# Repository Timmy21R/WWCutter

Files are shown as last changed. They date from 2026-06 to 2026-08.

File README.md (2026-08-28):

# WWCutter

Cross-platform four-axis hot-wire CAM and machine controller. It imports a
STEP solid or shell, finds (or lets the user select) its two end sections,
verifies that straight wire rulings reproduce the CAD surface, projects those
rulings to the XY and UV towers, and previews the complete machine motion.

## Setup

Python 3.11 or newer is recommended on Windows, macOS, and Linux.

```bash
conda activate foamcut
python -m pip install -r requirements.txt
python WWCutterV01.py
```

CadQuery includes Open Cascade and reads STEP units as millimetres. No native
compiler or platform-specific application changes are required when its wheel
is available for the selected Python version.

## STEP workflow

1. Select **Import STEP**. Ordinary two-section lofts are detected
   automatically.
2. If necessary, select different root and tip sections from their dropdowns.
   Open-shell boundary loops are also available in the two section lists.
3. Enter the tower spacing, distance from the left tower to the root face, and
   horizontal/vertical travel. Set the stock rotation about its span axis and
   its root-section center in the machine workspace. Stock-position controls
   are constrained to the range where both complete tower paths remain inside
   the configured travel and safety margin. Choose whether internal contours
   are ignored or cut through an entry slit.
4. Choose **Resulting cut surface** to inspect the complete surface swept by
   the physical wire, or **Complete machine** to see it in the tower workspace.
   Move the slider to inspect every individual wire position. Green and blue
   mark the two foam sections or tower paths; yellow is the current wire.
   Dense models are shown at reduced detail while rotating; this affects only
   the display, not the calculated cut.
5. With the heater off, use **Move to Cut Start** to perform the dashed
   positioning move shown in the machine preview.
6. A STEP job can start only when its measured ruled-surface deviation is no
   greater than the configured tolerance and all projected moves fit the
   workspace.

The **Manual axes / job origin** fields provide the four X, Y, U, and V target
coordinates used by **Go to Origin**. **Set Current as Origin** resets the
controller's current four-axis position and all four fields to zero. These
manual values do not offset or bypass validation of the generated STEP path.

Deviation is checked in both directions at intermediate span sections. This
catches STEP skins that bow between otherwise valid root and tip profiles—a
straight hot wire can create only a ruled surface. Ignored internal contours
do not contribute motion or deviation, and the preview labels the measurement
as outer-only. Through contours can be cut with an entry slit; blind contours
that do not reach both foam end faces remain blocked.

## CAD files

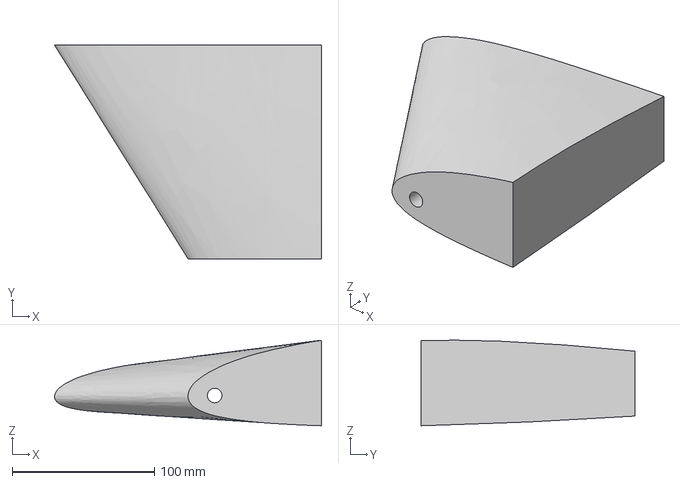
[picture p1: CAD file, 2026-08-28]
MasterSections.step
187.5 x 150.0 x 60.1 mm

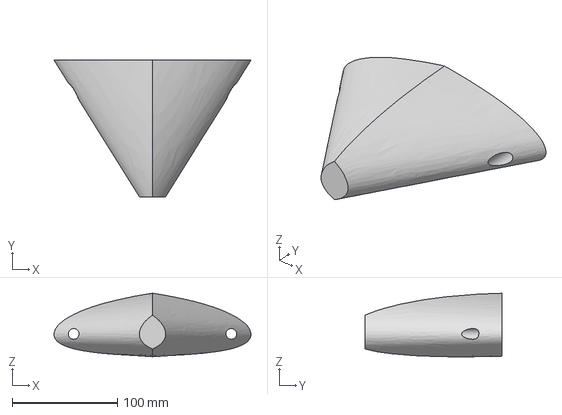
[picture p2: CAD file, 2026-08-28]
MasterSections12.step
187.5 x 130.0 x 60.5 mm

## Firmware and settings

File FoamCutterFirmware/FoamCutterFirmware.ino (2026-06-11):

#include <AccelStepper.h>
#include <MultiStepper.h>
#include <ctype.h>
#include <stdlib.h>
#include <string.h>

// Step/dir pins (CNC shield)
AccelStepper stepperX(AccelStepper::DRIVER, 2, 5);
AccelStepper stepperY(AccelStepper::DRIVER, 3, 6);
AccelStepper stepperU(AccelStepper::DRIVER, 4, 7);
AccelStepper stepperV(AccelStepper::DRIVER, 12, 13);
MultiStepper steppers;

// IO
#define ENABLE_PIN 8
#define X_LIMIT_PIN 9
#define Y_LIMIT_PIN 10
#define U_LIMIT_PIN 11
#define V_LIMIT_PIN A3

struct MachineConfig {
  long cutMaxSpeed = 2500;       // steps/sec
  long homeSpeed = 3200;         // steps/sec
  int homeDirection = -1;        // -1 or +1
  uint8_t homeSensorX = 0;       // 0=X, 1=Y, 2=U, 3=V
  uint8_t homeSensorY = 1;
  uint8_t homeSensorU = 2;
  uint8_t homeSensorV = 3;
};

struct MoveTarget {
  long x;
  long y;
  long u;
  long v;
  int speed;
};

MachineConfig config;
long positions[4];
const uint8_t MOVE_QUEUE_CAPACITY = 45;
const uint8_t MAX_INPUT_LINE_LENGTH = 64;
const unsigned long HOME_SWITCH_DEBOUNCE_MS = 10;
const unsigned long HOME_TIMEOUT_MS = 120000;
const unsigned long HOME_STATUS_INTERVAL_MS = 100;
MoveTarget moveQueue[MOVE_QUEUE_CAPACITY];
uint8_t moveQueueHead = 0;
uint8_t moveQueueTail = 0;
uint8_t moveQueueCount = 0;
bool moveActive = false;
bool motionPaused = false;
bool uploadJobActive = false;
long uploadExpectedMoves = 0;
long uploadAcceptedMoves = 0;
long uploadCompletedMoves = 0;
MoveTarget activeMove;

void enableDrivers() {
  digitalWrite(ENABLE_PIN, LOW);
}

void releaseDrivers() {
  digitalWrite(ENABLE_PIN, HIGH);
}

void trimInPlace(char *value) {
  if (!value) return;

  size_t length = strlen(value);
  size_t start = 0;
  while (start < length && isspace((unsigned char)value[start])) {
    start++;
  }

  size_t end = length;
  while (end > start && isspace((unsigned char)value[end - 1])) {
    end--;
  }

  if (start > 0) {
    memmove(value, value + start, end - start);
  }
  value[end - start] = '\0';
}

void toUpperInPlace(char *value) {
  if (!value) return;
  while (*value) {
    *value = (char)toupper((unsigned char)*value);
    value++;
  }
}

bool parseLongValue(const char *value, long &outValue) {
  if (!value) return false;
  while (*value && isspace((unsigned char)*value)) {
    value++;
  }
  if (*value == '\0') return false;

  char *endPtr = nullptr;
  long parsed = strtol(value, &endPtr, 10);
  if (endPtr == value) return false;
  while (*endPtr) {
    if (!isspace((unsigned char)*endPtr)) {
      return false;
    }
    endPtr++;
  }
  outValue = parsed;
  return true;
}

bool limitTriggered(int pin) {
  return digitalRead(pin) == HIGH;
}

void printStatus() {
  Serial.print(F("OK STATUS X="));
  Serial.print(limitTriggered(X_LIMIT_PIN) ? 1 : 0);
  Serial.print(F(" Y="));
  Serial.print(limitTriggered(Y_LIMIT_PIN) ? 1 : 0);
  Serial.print(F(" U="));
  Serial.print(limitTriggered(U_LIMIT_PIN) ? 1 : 0);
  Serial.print(F(" V="));
  Serial.println(limitTriggered(V_LIMIT_PIN) ? 1 : 0);
}

void applyCutSpeed() {
  long speed = config.cutMaxSpeed;
  if (speed < 100) speed = 100;
  stepperX.setMaxSpeed(speed);
  stepperY.setMaxSpeed(speed);
  stepperU.setMaxSpeed(speed);
  stepperV.setMaxSpeed(speed);
}

void printConfig() {
  Serial.print(F("CFG cutMaxSpeed=")); Serial.println(config.cutMaxSpeed);
  Serial.print(F("CFG homeSpeed=")); Serial.println(config.homeSpeed);
  Serial.print(F("CFG homeDirection=")); Serial.println(config.homeDirection);
  Serial.print(F("CFG homeSensorX=")); Serial.println(config.homeSensorX);
  Serial.print(F("CFG homeSensorY=")); Serial.println(config.homeSensorY);
  Serial.print(F("CFG homeSensorU=")); Serial.println(config.homeSensorU);
  Serial.print(F("CFG homeSensorV=")); Serial.println(config.homeSensorV);
  Serial.println(F("OK GETCFG"));
}

void setConfigValue(char *key, char *value) {
  trimInPlace(key);
  trimInPlace(value);
  toUpperInPlace(key);
  long parsed = 0;
  if (!parseLongValue(value, parsed)) {
    Serial.println(F("ERR CFG invalid-number"));
    return;
  }

  if (strcmp(key, "CUTMAXSPEED") == 0) {
    if (parsed < 100) parsed = 100;
    config.cutMaxSpeed = parsed;
    applyCutSpeed();
    Serial.print(F("OK CFG cutMaxSpeed=")); Serial.println(config.cutMaxSpeed);
    return;
  }
  if (strcmp(key, "HOMESPEED") == 0) {
    if (parsed < 100) parsed = 100;
    config.homeSpeed = parsed;
    Serial.print(F("OK CFG homeSpeed=")); Serial.println(config.homeSpeed);
    return;
  }
  if (strcmp(key, "HOMEDIRECTION") == 0) {
    config.homeDirection = parsed >= 0 ? 1 : -1;
    Serial.print(F("OK CFG homeDirection=")); Serial.println(config.homeDirection);
    return;
  }
  if (strcmp(key, "HOMESENSORX") == 0) {
    if (parsed < 0) parsed = 0;
    if (parsed > 3) parsed = 3;
    config.homeSensorX = parsed;
    Serial.print(F("OK CFG homeSensorX=")); Serial.println(config.homeSensorX);
    return;
  }
  if (strcmp(key, "HOMESENSORY") == 0) {
    if (parsed < 0) parsed = 0;
    if (parsed > 3) parsed = 3;
    config.homeSensorY = parsed;
    Serial.print(F("OK CFG homeSensorY=")); Serial.println(config.homeSensorY);
    return;
  }
  if (strcmp(key, "HOMESENSORU") == 0) {
    if (parsed < 0) parsed = 0;
    if (parsed > 3) parsed = 3;
    config.homeSensorU = parsed;
    Serial.print(F("OK CFG homeSensorU=")); Serial.println(config.homeSensorU);
    return;
  }
  if (strcmp(key, "HOMESENSORV") == 0) {
    if (parsed < 0) parsed = 0;
    if (parsed > 3) parsed = 3;
    config.homeSensorV = parsed;
    Serial.print(F("OK CFG homeSensorV=")); Serial.println(config.homeSensorV);
    return;
  }

  Serial.println(F("ERR CFG unknown-key"));
}

int limitPinForSensorIndex(int sensorIndex) {
  switch (sensorIndex) {
    case 0: return X_LIMIT_PIN;
    case 1: return Y_LIMIT_PIN;
    case 2: return U_LIMIT_PIN;
    case 3: return V_LIMIT_PIN;
    default: return X_LIMIT_PIN;
  }
}

bool parseMove(char *parts[], int offset, long coords[4]) {
  for (int i = 0; i < 4; i++) {
    if (!parseLongValue(parts[offset + i], coords[i])) {
      return false;
    }
  }
  return true;
}

int parseAxisIndex(char *value) {
  if (!value) {
    return -1;
  }

  trimInPlace(value);
  toUpperInPlace(value);
  if (strcmp(value, "X") == 0) return 0;
  if (strcmp(value, "Y") == 0) return 1;
  if (strcmp(value, "U") == 0) return 2;
  if (strcmp(value, "V") == 0) return 3;
  return -1;
}

long currentAxisPosition(int axisIndex) {
  switch (axisIndex) {
    case 0: return positions[0];
    case 1: return positions[1];
    case 2: return positions[2];
    case 3: return positions[3];
    default: return 0;
  }
}

void clearMoveQueue() {
  moveQueueHead = 0;
  moveQueueTail = 0;
  moveQueueCount = 0;
  moveActive = false;
  motionPaused = false;
  uploadJobActive = false;
  uploadExpectedMoves = 0;
  uploadAcceptedMoves = 0;
  uploadCompletedMoves = 0;
}

void syncStepperPositionsFromLogical() {
  stepperX.setCurrentPosition(positions[0]);
  stepperY.setCurrentPosition(positions[1]);
  stepperU.setCurrentPosition(positions[2]);
  stepperV.setCurrentPosition(positions[3]);
}

void syncLogicalPositionsFromSteppers() {
  positions[0] = stepperX.currentPosition();
  positions[1] = stepperY.currentPosition();
  positions[2] = stepperU.currentPosition();
  positions[3] = stepperV.currentPosition();
}

bool enqueueMove(long coords[4], long targetSpeed) {
  if (moveQueueCount >= MOVE_QUEUE_CAPACITY) {
    return false;
  }

  moveQueue[moveQueueTail].x = coords[0];
  moveQueue[moveQueueTail].y = coords[1];
  moveQueue[moveQueueTail].u = coords[2];
  moveQueue[moveQueueTail].v = coords[3];
  moveQueue[moveQueueTail].speed = targetSpeed; // <--- NEW
  
  moveQueueTail = (moveQueueTail + 1) % MOVE_QUEUE_CAPACITY;
  moveQueueCount++;
  return true;
}

bool dequeueMove(MoveTarget &target) {
  if (moveQueueCount == 0) {
    return false;
  }

  target = moveQueue[moveQueueHead];
  moveQueueHead = (moveQueueHead + 1) % MOVE_QUEUE_CAPACITY;
  moveQueueCount--;
  return true;
}

bool targetMatchesLogicalPosition(const MoveTarget &target) {
  return
    target.x == positions[0] &&
    target.y == positions[1] &&
    target.u == positions[2] &&
    target.v == positions[3];
}

void startNextQueuedMove() {
  if (motionPaused || moveActive || moveQueueCount == 0) {
    return;
  }

  while (moveQueueCount > 0 && !motionPaused && !moveActive) {
    if (!dequeueMove(activeMove)) {
      return;
    }

    if (targetMatchesLogicalPosition(activeMove)) {
      completeActiveMove();
      continue;
    }

    enableDrivers();
    positions[0] = activeMove.x;
    positions[1] = activeMove.y;
    positions[2] = activeMove.u;
    positions[3] = activeMove.v;
    
    // --- NEW: Apply the dynamic speed for this specific segment ---
    long stepSpeed = activeMove.speed;
    if (stepSpeed < 100) stepSpeed = 100;
    stepperX.setMaxSpeed(stepSpeed);
    stepperY.setMaxSpeed(stepSpeed);
    stepperU.setMaxSpeed(stepSpeed);
    stepperV.setMaxSpeed(stepSpeed);
    // --------------------------------------------------------------

    steppers.moveTo(positions);
    moveActive = true;
    return;
  }
}
void completeActiveMove() {
  moveActive = false;
  uploadCompletedMoves++;

  Serial.print(F("OK MOVE "));
  Serial.print(activeMove.x); Serial.print(",");
  Serial.print(activeMove.y); Serial.print(",");
  Serial.print(activeMove.u); Serial.print(",");
  Serial.println(activeMove.v);

  if (uploadJobActive &&
      uploadCompletedMoves >= uploadExpectedMoves &&
      moveQueueCount == 0) {
    uploadJobActive = false;
    Serial.print(F("OK UPDONE "));
    Serial.println(uploadCompletedMoves);
  }
}

void serviceMoveQueue() {
  if (motionPaused) {
    return;
  }

  if (!moveActive) {
    startNextQueuedMove();
  }

  if (!moveActive) {
    return;
  }

  if (!steppers.run()) {
    completeActiveMove();
    startNextQueuedMove();
  }
}

void pauseMotion() {
  motionPaused = true;
  Serial.println(F("OK PAUSE"));
}

void resumeMotion() {
  motionPaused = false;
  startNextQueuedMove();
  Serial.println(F("OK RESUME"));
}

void abortMotion() {
  syncLogicalPositionsFromSteppers();
  steppers.moveTo(positions);
  syncStepperPositionsFromLogical();
  clearMoveQueue();

  Serial.print(F("OK ABORT "));
  Serial.print(positions[0]); Serial.print(",");
  Serial.print(positions[1]); Serial.print(",");
  Serial.print(positions[2]); Serial.print(",");
  Serial.println(positions[3]);
}

void executeMove(long coords[4]) {
  if (coords[0] == positions[0] &&
      coords[1] == positions[1] &&
      coords[2] == positions[2] &&
      coords[3] == positions[3]) {
    Serial.print(F("OK MOVE "));
    Serial.print(coords[0]); Serial.print(",");
    Serial.print(coords[1]); Serial.print(",");
    Serial.print(coords[2]); Serial.print(",");
    Serial.println(coords[3]);
    return;
  }

  enableDrivers();
  positions[0] = coords[0];
  positions[1] = coords[1];
  positions[2] = coords[2];
  positions[3] = coords[3];

  steppers.moveTo(positions);
  steppers.runSpeedToPosition();

  Serial.print(F("OK MOVE "));
  Serial.print(positions[0]); Serial.print(",");
  Serial.print(positions[1]); Serial.print(",");
  Serial.print(positions[2]); Serial.print(",");
  Serial.println(positions[3]);
}

void jogAxis(int axisIndex, long delta) {
  if (axisIndex < 0 || axisIndex > 3) {
    Serial.println(F("ERR JOG invalid-axis"));
    return;
  }
  if (delta == 0) {
    Serial.println(F("ERR JOG zero-delta"));
    return;
  }

  enableDrivers();

  AccelStepper *stepper = nullptr;
  switch (axisIndex) {
    case 0: stepper = &stepperX; break;
    case 1: stepper = &stepperY; break;
    case 2: stepper = &stepperU; break;
    case 3: stepper = &stepperV; break;
    default: break;
  }

  if (!stepper) {
    Serial.println(F("ERR JOG invalid-axis"));
    return;
  }

  syncStepperPositionsFromLogical();
  const long target = positions[axisIndex] + delta;
  long speed = config.cutMaxSpeed;
  if (speed < 100) speed = 100;
  stepper->setCurrentPosition(positions[axisIndex]);
  stepper->setMaxSpeed(speed);
  stepper->moveTo(target);
  stepper->setSpeed(delta > 0 ? speed : -speed);

  while (stepper->distanceToGo() != 0) {
    stepper->runSpeedToPosition();
  }

  positions[axisIndex] = target;

  Serial.print(F("OK JOG "));
  Serial.print(positions[0]); Serial.print(",");
  Serial.print(positions[1]); Serial.print(",");
  Serial.print(positions[2]); Serial.print(",");
  Serial.println(positions[3]);
}

void syncPosition(long coords[4]) {
  positions[0] = coords[0];
  positions[1] = coords[1];
  positions[2] = coords[2];
  positions[3] = coords[3];

  stepperX.setCurrentPosition(positions[0]);
  stepperY.setCurrentPosition(positions[1]);
  stepperU.setCurrentPosition(positions[2]);
  stepperV.setCurrentPosition(positions[3]);
  clearMoveQueue();

  Serial.print(F("OK SETPOS "));
  Serial.print(positions[0]); Serial.print(",");
  Serial.print(positions[1]); Serial.print(",");
  Serial.print(positions[2]); Serial.print(",");
  Serial.println(positions[3]);
}

const uint8_t HOME_AXIS_SEEKING = 0;
const uint8_t HOME_AXIS_DEBOUNCING = 1;
const uint8_t HOME_AXIS_DONE = 2;

bool isHomeAxisDone(uint8_t state) {
  return state == HOME_AXIS_DONE;
}

void updateHomeAxis(AccelStepper &stepper,
                    int limitPin,
                    uint8_t &state,
                    unsigned long &debounceStartedAtMs) {
  if (state == HOME_AXIS_DONE) {
    return;
  }

  const bool limitActive = limitTriggered(limitPin);

  if (state == HOME_AXIS_DEBOUNCING) {
    if (!limitActive) {
      state = HOME_AXIS_SEEKING;
      debounceStartedAtMs = 0;
      stepper.setSpeed(config.homeDirection * config.homeSpeed);
      return;
    }

    if (millis() - debounceStartedAtMs >= HOME_SWITCH_DEBOUNCE_MS) {
      stepper.setSpeed(0);
      state = HOME_AXIS_DONE;
    }
    return;
  }

  if (limitActive) {
    stepper.setSpeed(0);
    if (HOME_SWITCH_DEBOUNCE_MS == 0) {
      state = HOME_AXIS_DONE;
    } else {
      state = HOME_AXIS_DEBOUNCING;
      debounceStartedAtMs = millis();
    }
    return;
  }

  stepper.runSpeed();
}

void homeMachine() {
  enableDrivers();
  const unsigned long homeStartedAtMs = millis();
  unsigned long lastHomeStatusAtMs = 0;

  const int xHomeLimitPin = limitPinForSensorIndex(config.homeSensorX);
  const int yHomeLimitPin = limitPinForSensorIndex(config.homeSensorY);
  const int uHomeLimitPin = limitPinForSensorIndex(config.homeSensorU);
  const int vHomeLimitPin = limitPinForSensorIndex(config.homeSensorV);

  stepperX.setMaxSpeed(config.homeSpeed);
  stepperY.setMaxSpeed(config.homeSpeed);
  stepperU.setMaxSpeed(config.homeSpeed);
  stepperV.setMaxSpeed(config.homeSpeed);

  // --- STAGE 1: Home X and U (Horizontal) ---
  stepperX.setSpeed(config.homeDirection * config.homeSpeed);
  stepperU.setSpeed(config.homeDirection * config.homeSpeed);
  
  uint8_t xState = limitTriggered(xHomeLimitPin) ? HOME_AXIS_DEBOUNCING : HOME_AXIS_SEEKING;
  uint8_t uState = limitTriggered(uHomeLimitPin) ? HOME_AXIS_DEBOUNCING : HOME_AXIS_SEEKING;
  
  unsigned long xDebounceStartedAtMs = xState == HOME_AXIS_DEBOUNCING ? homeStartedAtMs : 0;
  unsigned long uDebounceStartedAtMs = uState == HOME_AXIS_DEBOUNCING ? homeStartedAtMs : 0;

  while (!isHomeAxisDone(xState) || !isHomeAxisDone(uState)) {
    const unsigned long nowMs = millis();
    if (lastHomeStatusAtMs == 0 || nowMs - lastHomeStatusAtMs >= HOME_STATUS_INTERVAL_MS) {
      printStatus();
      lastHomeStatusAtMs = nowMs;
    }
    if (nowMs - homeStartedAtMs >= HOME_TIMEOUT_MS) {
      applyCutSpeed(); clearMoveQueue(); Serial.println(F("ERR HOME timeout")); return;
    }
    updateHomeAxis(stepperX, xHomeLimitPin, xState, xDebounceStartedAtMs);
    updateHomeAxis(stepperU, uHomeLimitPin, uState, uDebounceStartedAtMs);
  }

  // --- STAGE 2: Home Y and V (Vertical) ---
  stepperY.setSpeed(config.homeDirection * config.homeSpeed);
  stepperV.setSpeed(config.homeDirection * config.homeSpeed);
  
  uint8_t yState = limitTriggered(yHomeLimitPin) ? HOME_AXIS_DEBOUNCING : HOME_AXIS_SEEKING;
  uint8_t vState = limitTriggered(vHomeLimitPin) ? HOME_AXIS_DEBOUNCING : HOME_AXIS_SEEKING;
  
  unsigned long yDebounceStartedAtMs = yState == HOME_AXIS_DEBOUNCING ? millis() : 0;
  unsigned long vDebounceStartedAtMs = vState == HOME_AXIS_DEBOUNCING ? millis() : 0;

  while (!isHomeAxisDone(yState) || !isHomeAxisDone(vState)) {
    const unsigned long nowMs = millis();
    if (lastHomeStatusAtMs == 0 || nowMs - lastHomeStatusAtMs >= HOME_STATUS_INTERVAL_MS) {
      printStatus();
      lastHomeStatusAtMs = nowMs;
    }
    if (nowMs - homeStartedAtMs >= HOME_TIMEOUT_MS) {
      applyCutSpeed(); clearMoveQueue(); Serial.println(F("ERR HOME timeout")); return;
    }
    updateHomeAxis(stepperY, yHomeLimitPin, yState, yDebounceStartedAtMs);
    updateHomeAxis(stepperV, vHomeLimitPin, vState, vDebounceStartedAtMs);
  }

  // --- STAGE 3: Finalize ---
  stepperX.setCurrentPosition(0);
  stepperY.setCurrentPosition(0);
  stepperU.setCurrentPosition(0);
  stepperV.setCurrentPosition(0);
  positions[0] = 0; positions[1] = 0; positions[2] = 0; positions[3] = 0;
  
  applyCutSpeed();
  clearMoveQueue();
  printStatus();
  Serial.println(F("OK HOME"));
}

void dispatchLine(char *line) {
  trimInPlace(line);
  if (line[0] == '\0') {
    return;
  }

  char *parts[8];
  int partCount = 0;
  char *context = nullptr;
  char *token = strtok_r(line, ",", &context);
  while (token && partCount < 8) {
    trimInPlace(token);
    parts[partCount++] = token;
    token = strtok_r(nullptr, ",", &context);
  }
  if (partCount <= 0) return;

  char *command = parts[0];
  toUpperInPlace(command);
  long coords[4];

  // Backward-compatible raw move: X,Y,U,V
  if (partCount == 4 && parseMove(parts, 0, coords)) {
    executeMove(coords);
    return;
  }

  if (strcmp(command, "UPLOAD") == 0) {
    if (partCount < 2) {
      Serial.println(F("ERR UPLOAD invalid-format"));
      return;
    }

    long expected = 0;
    if (!parseLongValue(parts[1], expected) || expected <= 0) {
      Serial.println(F("ERR UPLOAD invalid-count"));
      return;
    }

    clearMoveQueue();
    uploadJobActive = true;
    uploadExpectedMoves = expected;
    Serial.print(F("OK UPLOAD "));
    Serial.print(uploadExpectedMoves);
    Serial.print(F(" CAP="));
    Serial.println(MOVE_QUEUE_CAPACITY);
    return;
  }

  if (strcmp(command, "QUEUE") == 0) {
    if (partCount < 5 || !parseMove(parts, 1, coords)) {
      Serial.println(F("ERR QUEUE invalid-format"));
      return;
    }
    
    // Default to the UI's base speed, but overwrite if Python sends a dynamic speed
    long targetSpeed = config.cutMaxSpeed; 
    if (partCount >= 6) {
        parseLongValue(parts[5], targetSpeed);
    }
    
    if (!uploadJobActive) {
      Serial.println(F("ERR QUEUE no-upload"));
      return;
    }
    if (uploadAcceptedMoves >= uploadExpectedMoves) {
      Serial.println(F("ERR QUEUE overflow"));
      return;
    }
    if (!enqueueMove(coords, targetSpeed)) {
      Serial.println(F("ERR QUEUE full"));
      return;
    }

    uploadAcceptedMoves++;
    Serial.print(F("OK QUEUE "));
    Serial.print(uploadAcceptedMoves);
    Serial.print("/");
    Serial.print(uploadExpectedMoves);
    Serial.print(F(" BUF="));
    Serial.println(moveQueueCount + (moveActive ? 1 : 0));
    startNextQueuedMove();
    return;
  }

  if (strcmp(command, "SETPOS") == 0) {
    if (partCount < 5 || !parseMove(parts, 1, coords)) {
      Serial.println(F("ERR SETPOS invalid-format"));
      return;
    }
    syncPosition(coords);
    return;
  }

  if (strcmp(command, "MOVE") == 0) {
    if (partCount < 5 || !parseMove(parts, 1, coords)) {
      Serial.println(F("ERR MOVE invalid-format"));
      return;
    }
    executeMove(coords);
    return;
  }

  if (strcmp(command, "JOG") == 0) {
    if (partCount < 3) {
      Serial.println(F("ERR JOG invalid-format"));
      return;
    }
    const int axisIndex = parseAxisIndex(parts[1]);
    long delta = 0;
    if (axisIndex < 0 || !parseLongValue(parts[2], delta)) {
      Serial.println(F("ERR JOG invalid-format"));
      return;
    }
    jogAxis(axisIndex, delta);
    return;
  }

  if (strcmp(command, "HOME") == 0) {
    homeMachine();
    return;
  }

  if (strcmp(command, "PAUSE") == 0) {
    pauseMotion();
    return;
  }

  if (strcmp(command, "RESUME") == 0) {
    resumeMotion();
    return;
  }

  if (strcmp(command, "ABORT") == 0) {
    abortMotion();
    return;
  }

  if (strcmp(command, "CFG") == 0) {
    if (partCount < 3) {
      Serial.println(F("ERR CFG invalid-format"));
      return;
    }
    setConfigValue(parts[1], parts[2]);
    return;
  }

  if (strcmp(command, "GETCFG") == 0) {
    printConfig();
    return;
  }

  if (strcmp(command, "STATUS") == 0) {
    printStatus();
    return;
  }

  if (strcmp(command, "RELEASE") == 0) {
    releaseDrivers();
    Serial.println(F("OK RELEASE"));
    return;
  }

  if (strcmp(command, "PING") == 0) {
    Serial.println(F("OK PONG"));
    return;
  }

  Serial.println(F("ERR unknown-command"));
}
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
void loop() {
  static char inputLine[MAX_INPUT_LINE_LENGTH];
  static uint8_t inputLength = 0;

  while (Serial.available()) {
    char c = (char)Serial.read();
    if (c == '\r' || c == '\n') {
      inputLine[inputLength] = '\0';
      trimInPlace(inputLine);
      if (inputLine[0] != '\0') {
        dispatchLine(inputLine);
      }
      inputLength = 0;
      inputLine[0] = '\0';
    } else {
      if (inputLength < MAX_INPUT_LINE_LENGTH - 1) {
        inputLine[inputLength++] = c;
        inputLine[inputLength] = '\0';
      } else {
        inputLength = 0;
        inputLine[0] = '\0';
        Serial.println(F("ERR LINE overflow"));
      }
    }
  }

  serviceMoveQueue();
}

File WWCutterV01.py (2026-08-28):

import sys
import time
from pathlib import Path
import numpy as np
import serial.tools.list_ports
from PyQt6.QtWidgets import (QApplication, QMainWindow, QPushButton, QVBoxLayout, 
                             QWidget, QSlider, QLabel, QFileDialog, QHBoxLayout, 
                             QDoubleSpinBox, QSpinBox, QComboBox, QGridLayout,
                             QGroupBox, QScrollArea)
from PyQt6.QtCore import Qt, QTimer, QThread, pyqtSignal

from cad_preview import CADPreview
from cad_toolpath import (CADGeometryError, CADImportError, MachineGeometry,
                          auto_detect_section_pair, build_cad_toolpath,
                          load_step_model)

class HomingWorker(QThread):
    finished = pyqtSignal()
    
    def __init__(self, serial_conn):
        super().__init__()
        self.serial_conn = serial_conn
        self.is_running = True

    def run(self):
        self.serial_conn.write(b"HOME\n")
        while self.is_running:
            if self.serial_conn.in_waiting:
                line = self.serial_conn.readline().decode('utf-8', errors='ignore').strip()
                if "OK HOME" in line:
                    break
        self.finished.emit()
        
    def stop(self):
        self.is_running = False

class HotWireController(QMainWindow):
    # Hardware calibration from machine coordinates to motor steps.
    STEPS_PER_MM = 1309.6  
    MAX_SEGMENT_MM = 1.0

    def __init__(self):
        super().__init__()
        self.setWindowTitle("WWCutter — Four-Axis Hot-Wire CAM")
        self.serial_conn = None
        self.step_model = None
        self.cad_path = None
        self.cad_valid = False
        self.cad_rebuild_timer = QTimer(self)
        self.cad_rebuild_timer.setSingleShot(True)
        self.cad_rebuild_timer.setInterval(140)
        self.cad_rebuild_timer.timeout.connect(self.rebuild_cad_toolpath)
        self.setup_ui()
        
        self.timer = QTimer()
        self.timer.timeout.connect(self.poll_status)
        self.timer.start(500)
        
        self.auto_connect()

    def setup_ui(self):
        layout = QVBoxLayout()
        header = QHBoxLayout()
        self.status_label = QLabel("Status: Disconnected")
        self.time_label = QLabel("Est. Job Time: 0s")
        header.addWidget(self.status_label, 1)
        header.addWidget(self.time_label)
        layout.addLayout(header)

        motion = QHBoxLayout()
        motion.addWidget(QPushButton("Home", clicked=self.home_machine))
        self.start_button = QPushButton("Start Job", clicked=self.start_job)
        motion.addWidget(self.start_button)
        motion.addWidget(QPushButton("Stop", clicked=self.stop_machine))
        motion.addWidget(QPushButton("Go to Origin", clicked=self.go_to_origin))
        motion.addWidget(QPushButton("Move to Cut Start", clicked=self.go_to_cut_start))
        motion.addWidget(QPushButton("Set Current as Origin", clicked=self.set_current_as_origin))
        layout.addLayout(motion)

        manual_group = QGroupBox("Manual axes / job origin (mm)")
        manual_layout = QHBoxLayout(manual_group)
        for axis_name in ("X", "Y", "U", "V"):
            manual_layout.addWidget(QLabel(
                "Job Origin X (mm):" if axis_name == "X" else "{}:".format(axis_name)
            ))
            box = QDoubleSpinBox()
            box.setRange(-2000.0, 2000.0)
            box.setDecimals(2)
            box.setSuffix(" mm")
            setattr(self, "origin_{}".format(axis_name.lower()), box)
            manual_layout.addWidget(box)
        manual_group.setToolTip(
            "Enter absolute X/Y/U/V machine coordinates, then choose Go to "
            "Origin. These values do not offset the validated STEP toolpath."
        )
        layout.addWidget(manual_group)

        cad_group = QGroupBox("STEP model")
        cad_layout = QGridLayout(cad_group)
        cad_layout.addWidget(QPushButton("Import STEP…", clicked=self.load_step), 0, 0)
        cad_layout.addWidget(QPushButton("Auto-detect End Faces", clicked=self.select_auto_sections), 0, 1)
        self.step_name = QLabel("No STEP model loaded")
        cad_layout.addWidget(self.step_name, 0, 2, 1, 3)

        cad_layout.addWidget(QLabel("Root section:"), 1, 0)
        self.root_section = QComboBox()
        self.root_section.currentIndexChanged.connect(self.rebuild_cad_toolpath)
        cad_layout.addWidget(self.root_section, 1, 1, 1, 4)

        cad_layout.addWidget(QLabel("Tip section:"), 2, 0)
        self.tip_section = QComboBox()
        self.tip_section.currentIndexChanged.connect(self.rebuild_cad_toolpath)
        cad_layout.addWidget(self.tip_section, 2, 1, 1, 4)
        layout.addWidget(cad_group)

        machine_group = QGroupBox("Machine and stock (mm)")
        machine_layout = QGridLayout(machine_group)

        def geometry_box(value, minimum, maximum, on_change=None):
            box = QDoubleSpinBox()
            box.setRange(minimum, maximum)
            box.setDecimals(1)
            box.setValue(value)
            box.valueChanged.connect(on_change or self.schedule_cad_rebuild)
            return box

        self.tower_span = geometry_box(1000.0, 10.0, 10000.0)
        self.foam_left_gap = geometry_box(100.0, 0.0, 10000.0)
        self.horizontal_travel = geometry_box(1000.0, 10.0, 10000.0)
        self.vertical_travel = geometry_box(1000.0, 10.0, 10000.0)
        self.workspace_margin = geometry_box(10.0, 0.0, 500.0)
        self.surface_tolerance = geometry_box(
            0.5, 0.01, 20.0, self.update_cad_validation
        )
        for column, (label, widget) in enumerate((
            ("Tower spacing", self.tower_span),
            ("Left tower → root", self.foam_left_gap),
            ("Horizontal travel", self.horizontal_travel),
            ("Vertical travel", self.vertical_travel),
            ("Safety margin", self.workspace_margin),
            ("Allowed deviation", self.surface_tolerance),
        )):
            machine_layout.addWidget(QLabel(label), 0, column)
            machine_layout.addWidget(widget, 1, column)
        machine_layout.addWidget(QLabel("Interior rods / contours"), 2, 0)
        self.interior_features = QComboBox()
        self.interior_features.addItem("Ignore them", False)
        self.interior_features.addItem("Cut out with entry slit", True)
        self.interior_features.setToolTip(
            "Ignoring measures and cuts only the outer skin. Cutting requires "
            "the contour to pass through both foam end faces."
        )
        self.interior_features.currentIndexChanged.connect(
            self.schedule_cad_rebuild
        )
        machine_layout.addWidget(self.interior_features, 2, 1)
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

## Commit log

2026-06-12 Add gitignore and remove unneeded files.
    [Front Spar Cover V01.dxf, Proto1 Wing profile 01.dxf]
2026-06-12 Address unwanted lines error experienced by Yang.
    [WWCutterV01.py]
2026-06-14 Made even different A and B profiles have synchronized progress, thus possibly allowing for tapered wings to be cut. Also added in a test file to detect regressions in the future.
2026-08-28 Initial attempt at 4 axis cutter ability.
    [MasterSections.step, MasterSections12.step]
